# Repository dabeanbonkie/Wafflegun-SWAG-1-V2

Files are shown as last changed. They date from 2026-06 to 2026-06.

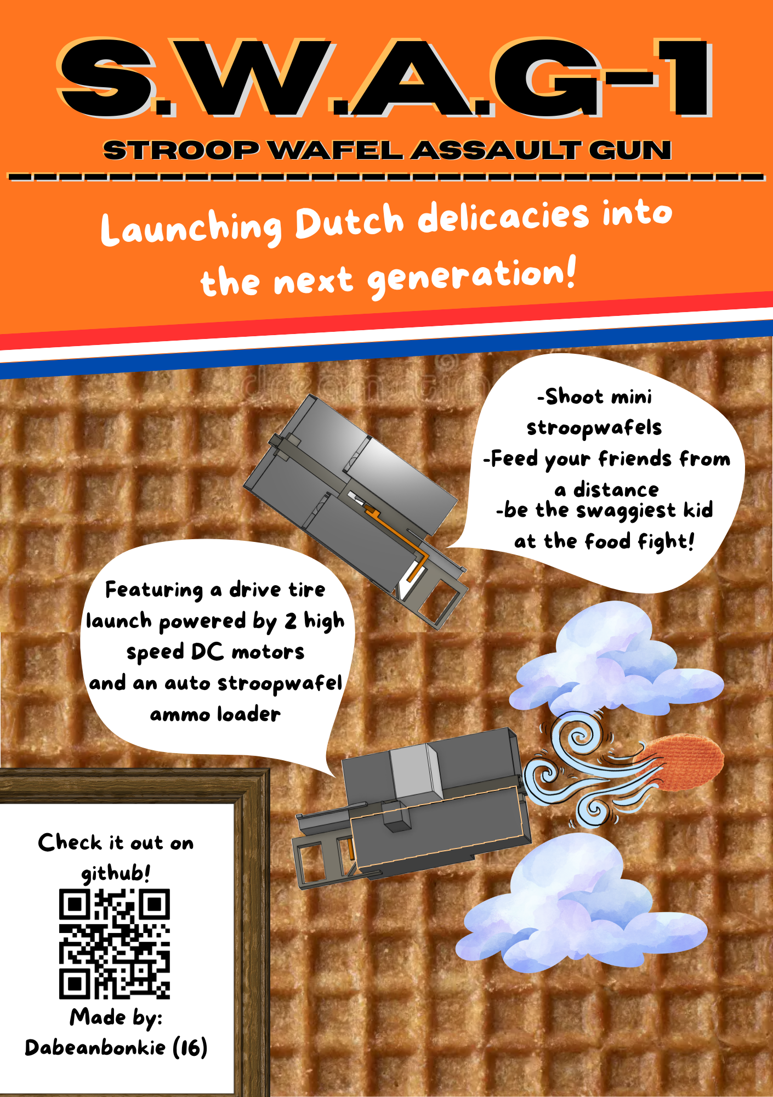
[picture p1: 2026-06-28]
S.W.A.G-1.png

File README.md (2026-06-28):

# Wafflegun-SWAG-1

S W A G-1

# Description
The S.W.A.G (Stroop-Wafel-Assault-Gun) is the latest generation of food based arms. It is a tire driven stroopwafel launcher with an auto loading system. It uses two motors for the launch and a servo for the loader and runs on a Xiao RP2040. The wafflegun can be used to hand out stroopwafels to an entire group from a distance within the span of just a couple seconds.

# Assembly
TO assemble the S.W.A.G start off by ordering the pcb from any shop you prefer, although i will explain how i ordered it using JLCPCB. Log in to JLCPCB and the hit "Order Now". From there you will be asked to add the gerber ZIP file from the repo. This will give you everything you need and the board should load on the site. Dont change anything for the rest of the order process, just hit next after you've added the gerber files zip. Following this pay for your pcb and then you're all done with the pcb until its delivered to you.

It should look like this is JLCPCB:



Note: I will be refering to the side of the pcb with the letters as the top and from there i call the other sides left, right and bottom. This is also diferent from the side of the pcb as in the working layer.

When the pcb arrives grab a BD139 NPN-transistor and place it in the holes near the left side if the pcb with the white part facing towards the inside of the pcb (pictued in example 1). Then Solder the legs of the transistor to the pcb from the bottom side while making sure no bridges are made (pictured in example 2). Then cut off the legs until the point they are soldered at (pictured in example 3)

Example 1:



Example 2:



Example 3:



Next grab all your curved pin headers, I used male dupont surved pin headers in my example because those were the ones i had, but i would recomend using female dupont curved pin headers. Both are fine so use whichever one you have but if you have to order them, order the female headers. You should have 3: 1 * 2 headers and 2: 1 * 3 headers. Put each of the pin headers in the hole that corresponds to the width (pictured in example 4). Then as with the transistor, solder each pin from the bottom side to the pcb (pictured in example 5).

Example 4:



Example 5:



Now here comes the hard part, were using a tiny 1.5K ohm SMD-0402 resistor. For the next two solders we will be using solder paste as its really the only way to get a solder this precise. I would also recomend using a magnfying glass at this point as this resistor is very small. Place two small bits of solder paste on the two pads on which we will solder the resistor (pictured in example 6). Then incredibly gently place the resistor on the two pads with the resistors black side facing up and use a heat gun to carefully melt the solder while making sure not to stay in one place too long as not to melt the pcb. The final result should look like example 7.

Example 6:



Example 7:



Lastly grab your solder paste again, and place a small glob on each of the solder pads for XIAO RP2040 (pictured in example 8). Then carefully place the XIAO RP2040 on top of the pads making sure each connection lines up with the micro-usb port facing towards the right side of the pcb (pictured in example 9). Then gently move the heatgun over the pcb to melt the solder while making sure not to melt the pcb or any other nearby components. The final result should look like example 9.

Example 8:


ELFR1021
Example 9:



You are now done with making the PCB for S.W.A.G-1

Kicad wiring schematic of the pcb:



Kicad wiring schematic of the full circuit:



To build the rest of the cuircuit start by grabbing your ELFR1021 DC high speed motors and cutting off the connector that is attached. After this crimp a dupont header on each wire of both of the motors. If you have used Female headers on the pcb, use male headers on the motors. If you have used male headers (like me) on the pcb use female headers on the motors. 

It should look like this:



After this attach red wire of both motors to the pinheaders group 5 on the pcb, and the black wires to the pinheader group 3 on the pcb.

It should look like this:



Next take your SG90 servo and attach it to pinheader group 2 on the pcb with the brown wire of the servo (GND wire) being attached to the right-sided pin on pinheader group 2. If the brown wire is on the right pin, the red and yellow wire are too.

It should look like this:



Following this i dont have a good physical example for the buttons. In the wiring diagram i show a SW-SP3T three way switch where one position is floating so no signal goes through the buttons meaning no part is turned on, and the other two positions going to either the motor or the servo so you can toggle the motor and servo separately. I do not have an SW_SP3T available due to a shipping error so the best i can do is show how to connect it. 

-First connect the right pin on pin header group 4 to the COM Pin ( also knows as the common pin and pin 3 on the wiring diagram showed earlier.). The brown wire is the wire you would connect to the common pin of the SW_SP3T.



-Then connect output 1 on the SW-SP3T to the middle pin on pinheader group 4 on the pcb and connect output 2 on the SW-SP3T to the left pin on pinheader group 4 on the pcb.

-Ouput 3 will be left floating as that will be the "off" pin so it has no output.

If you do all of this you can switch between turning on the servo, turning on the motor & having both off.

Next up take your 4*AA battery holder and if necessary crimp on female dupont headers to both wires if you have male headers on your pcb and male headers to both wires if you have female headers on your pcb.

It should look like this:


Then attach the red wire to specifically the right-sided pin on pin header ground 1 on the pcb, and the black wire to the lift sided pin  on pin header ground 1 on the pcb.

It should look like this:



With this all the wiring is done! Now on to the 3D-printed parts.

Start by printing all of the pieces in the STL files folder. The gear pieces need to be printed twice but all of the other pieces need to be printed only once.

Start by grabbing both "gear and wheel support" pieces and add 7 bearings with a 6mm inner diameter and a 13mm outer diameter to each support. Make sure to leave one hole on the far side with the extention empty as that one wont hold a gear.

It should look like this:



After that start adding your gears. Start by adding gear 1 to the first bearing from the side with the extention. Make sure to add the bearing to the flat side of the support, otherwise it will not fit.



After this add gear 2 to the bearing beside gear 1:



Then add gear 3 beside gear 2:



Then add gear 4 beside gear 3:



Then add gear 5 beside gear 4:



Then add gear A beside gear 5:



Then add gear B beside gear A:



Now repeat this exactly on the other support.

Next up, use Plastic glue to glue together barrel 1 and barrel 2. You can use glue here as these pieces never need to be seperated and are only seperate for easy of printing.

It should look roughly like this:



After this glue on the two gear and wheel support pieces making it so the side with the extention on the supports is on the wide side of the barrel with the lip. If that doesnt make sense i understand so ill show two angles of this step:





Next grab Support piece 2 with the stock attached, and slide it through the bottom square hole of the barrel. No glue required as this part might need to be seperated for maintenence. For this step i will also add 2 angles:





Then grab Support piece 1 and do the same as with support piece 2, exept this time on the top square hole and without the stock.



Following this add the PCB and Battery holder to the back of the barrel, glue is optional, you could add it if it falls off but if placed right it should fit nice and snug. For this i will again add two angles for clarity:





The next step is adding the actual electronics. First take the pcb and add it to the pcb holder (i left my battery unconnected cause its more dificult to add the pcb to the holder with the battery attached):

it should look like this:



Next add the battery on top of the pcb holder. 



After this add the motors under the extention on the gear and wheel supports, it should be a snug fit. Also remember to make sure the connector from gear 1 and the connector on the motor line up



Do the same on the other gear and wheel support.

Now add the 65mm rubber wheels to the "gear B" gears on both supports. It should be a snug fit.



Then its time to add the shells. Grab shell 1 and 2 and attach them to the barrel with them also snugly fitting around the support pieces. I will add three angles cause this can be really tricky:







Next up its time for the waffle magazine piece, i recomend laying the wafflegun on its side for this portion as the glue will dry easier without it falling if its on its side. So start off by finding the hole that the magazine attaches to and putting some plastic glue on the edges before placing on the magazine making sure that the holes are alligned on both.

This is where the hole for the magazine is:



this is how to place it:



After this its time to add the servo holder. Keep the wafflegun on its side for this part. This part has to attach right next to the the magazine. Using plastic glue, glue this part to Shell-2 as that is where the part has the largest surface area of contact.



Next up place the servo inside the servo holder, i have no physical images for this so ill try to explain how to place it. Place the servo inside the holder while making sure the wires at the back of the servo are facing the hole next to the hole for the waffle magazine.

This is the hole to put all the wires for the servo through:



Then take the wires and push them through the barrel towards the pcb, where you can connect it to the coresponding pins. The Arm of the servo should fit into the hole in the magazine itself

This is the hole the servo arm goes through:



The servo arm can then push stroopwafels into the barrel as another falls into place to replace the one thats been loaded, thus making the autoloading work.

The last piece of the puzzle is the waffle pusher, which pushes the stroopwafel to the drive tires that it gets shot from. To place it go to the side opposite of the waffle magazine  and push the long pusher piece into the hole with the tail of the piece leading to the grip and stock so you can push the waffles from where you hand is holding the S.W.A.G-1.



And now you are (finally) done with building S.W.A.G-1

# Onshape Link for the shell:

https://cad.onshape.com/documents/747ccfec51634792c2777cca/w/01fb49ed376507a91ea61a49/e/87ecc3b4d7d030e5be71dfa8

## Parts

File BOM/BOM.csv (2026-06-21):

Reference | Qty | Value | DNP | Exclude from BOM | Exclude from Board | Footprint | Datasheet
J1,J3 | 2 | Conn_01x03 |  |  |  | Connector_PinSocket_2.54mm:PinSocket_1x03_P2.54mm_Horizontal
J2,J4,J5 | 3 | Conn_01x02 |  |  |  | Connector_PinSocket_2.54mm:PinSocket_1x02_P2.54mm_Horizontal
Q1 | 1 | BD139 |  |  |  | Package_TO_SOT_THT:TO-126-3_Vertical | http://www.st.com/internet/com/TECHNICAL_RESOURCES/TECHNICAL_LITERATURE/DATASHEET/CD00001225.pdf
R1 | 1 | 1.5K |  |  |  | Resistor_SMD:R_0402_1005Metric
U1 | 1 | XIAO-RP2040-SMD |  |  |  | seeed:XIAO-RP2040-SMD

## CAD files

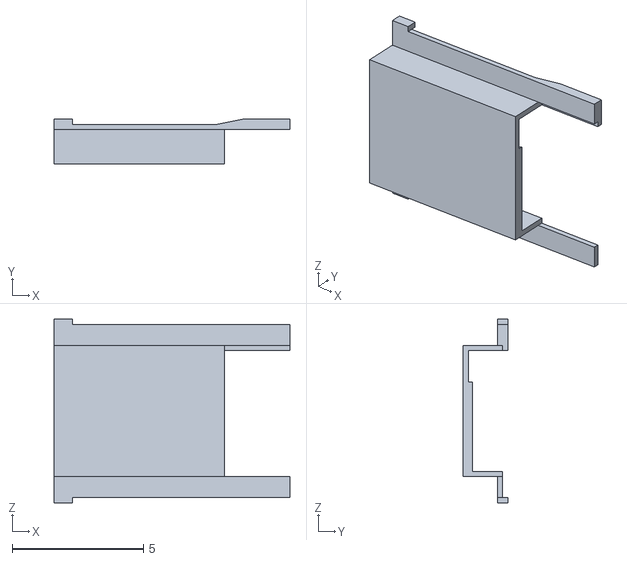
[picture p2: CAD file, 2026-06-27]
STL files Wafflegun/S.W.A.G-1 Wafflegun - PCB & Battery holder.stl
9.00 x 1.70 x 7.00

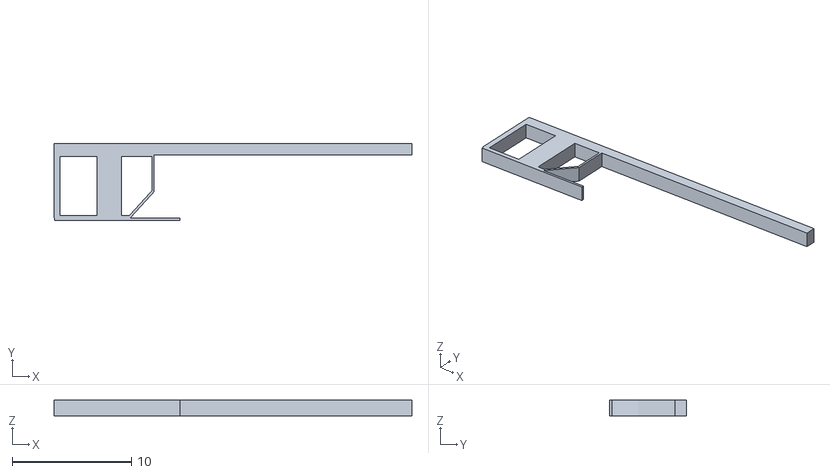
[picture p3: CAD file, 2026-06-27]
STL files Wafflegun/S.W.A.G-1 Wafflegun - Support Piece 2 + Stock.stl
30.0 x 6.42 x 1.30

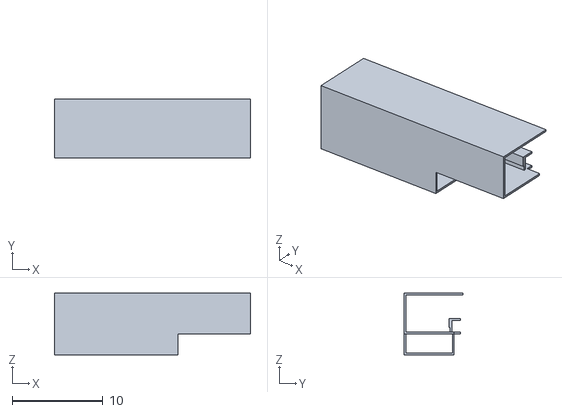
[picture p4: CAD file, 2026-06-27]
STL files Wafflegun/S.W.A.G-1 Wafflegun - Shell 2.stl
21.6 x 6.45 x 6.80

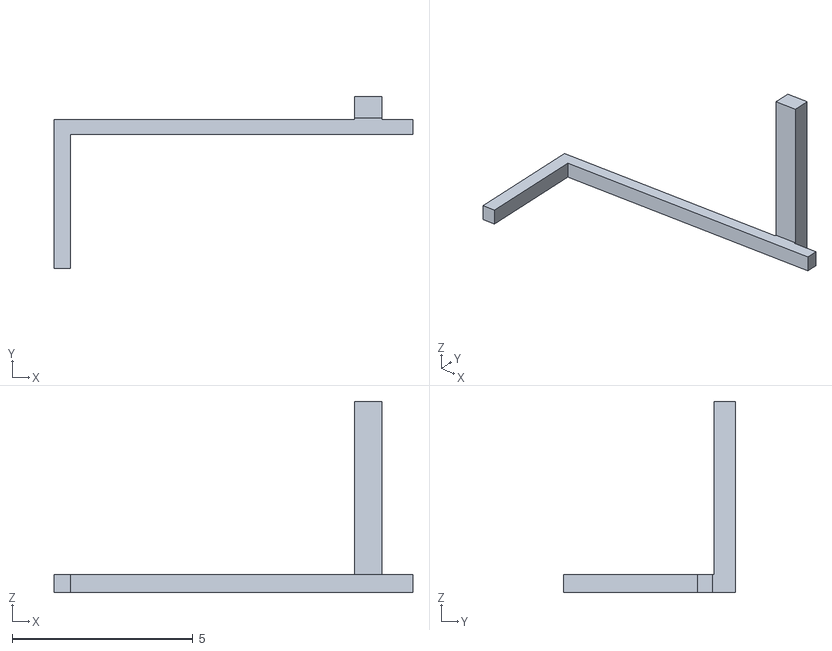
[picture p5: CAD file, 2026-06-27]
STL files Wafflegun/S.W.A.G-1 Wafflegun - Waffle pusher.stl
9.94 x 4.77 x 5.30

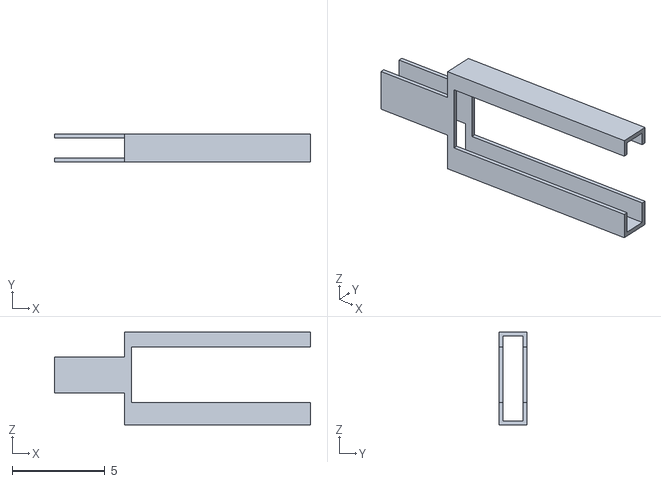
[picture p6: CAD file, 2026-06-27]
STL files Wafflegun/S.W.A.G-1 Wafflegun - Barrel 2.stl
13.8 x 1.50 x 5.00

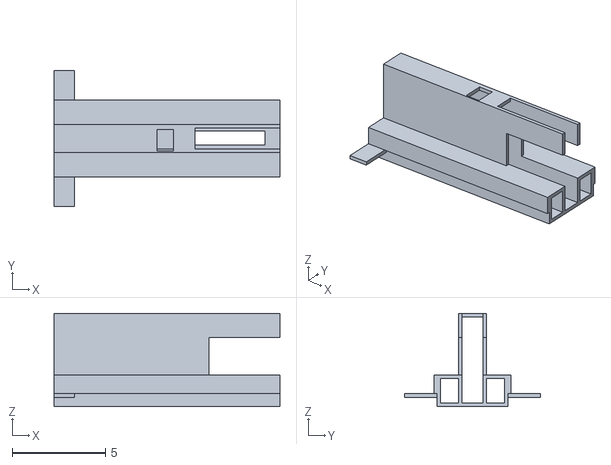
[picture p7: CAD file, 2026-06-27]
STL files Wafflegun/S.W.A.G-1 Wafflegun - Barrel 1.stl
12.1 x 7.30 x 5.00

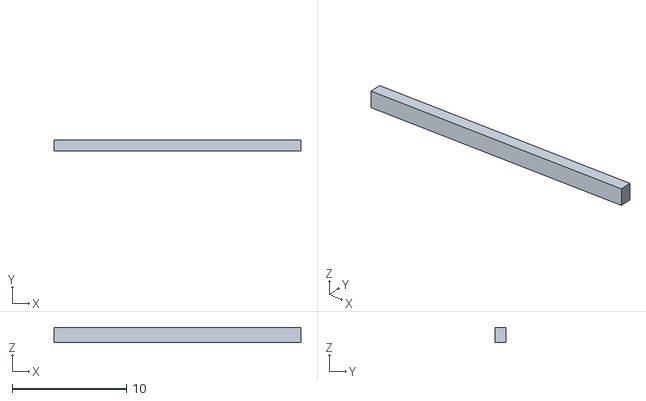
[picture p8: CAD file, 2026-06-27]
STL files Wafflegun/S.W.A.G-1 Wafflegun - Support piece 1.stl
21.6 x 0.952 x 1.30

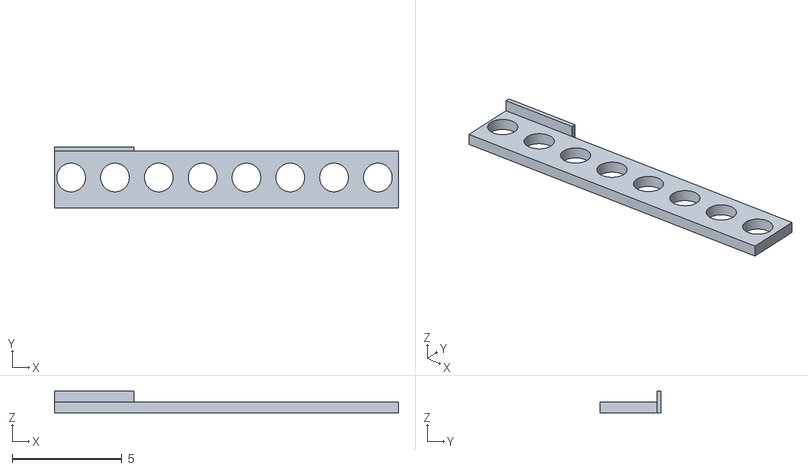
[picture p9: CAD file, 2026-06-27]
STL files Wafflegun/S.W.A.G-1 Wafflegun - Gear and Wheel Support 1.stl
15.7 x 2.80 x 1.00

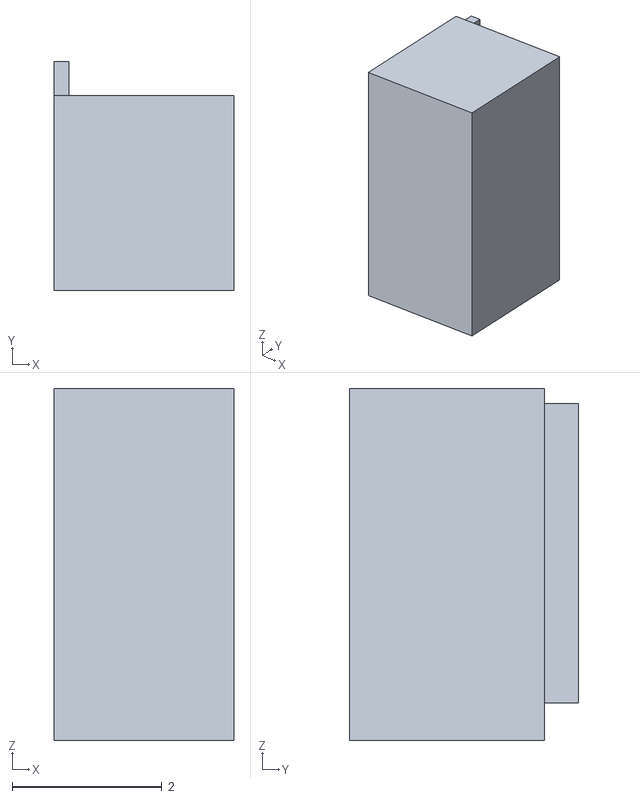
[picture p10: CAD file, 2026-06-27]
STL files Wafflegun/S.W.A.G-1 Wafflegun - Servo Holder.stl
2.40 x 3.05 x 4.70

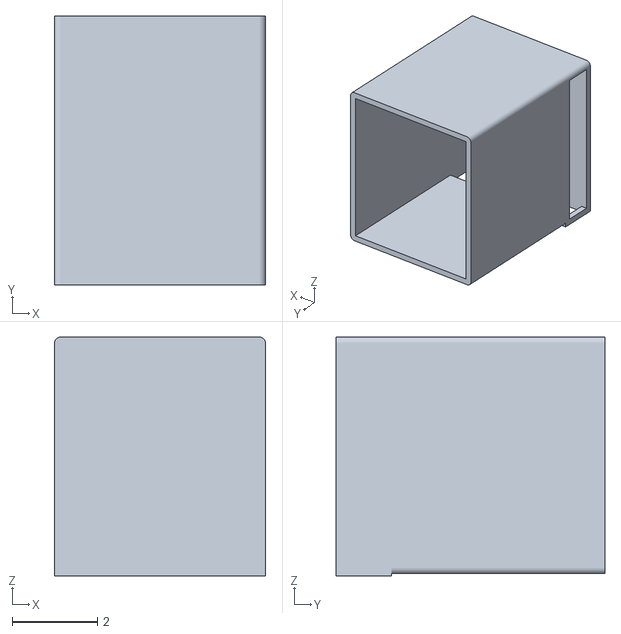
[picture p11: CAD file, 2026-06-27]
STL files Wafflegun/S.W.A.G-1 Wafflegun - Waffle Magazine.stl
4.95 x 6.30 x 5.60

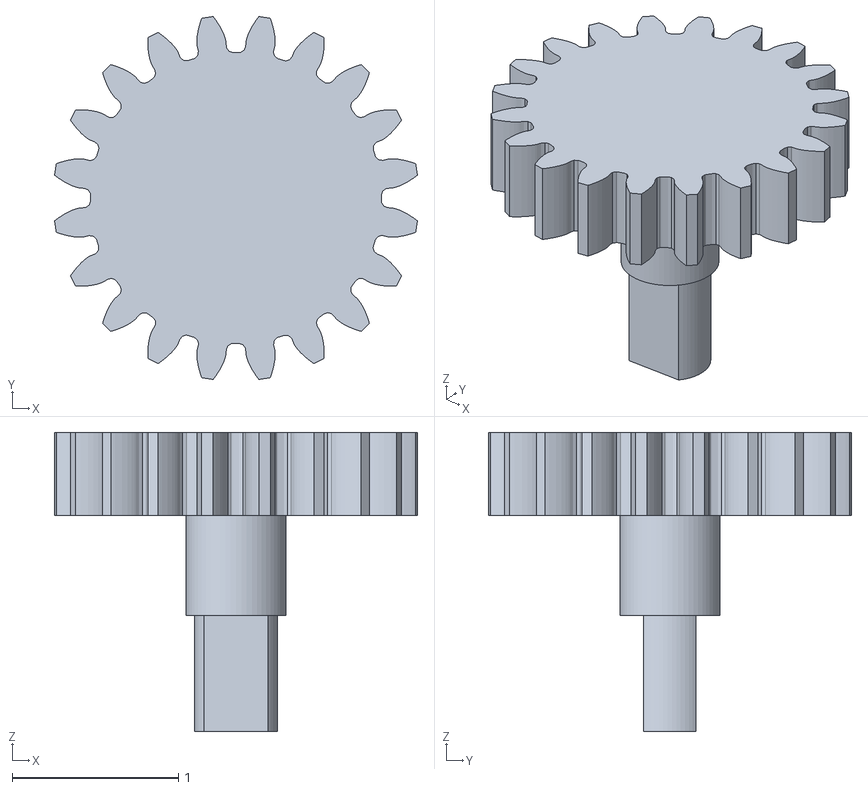
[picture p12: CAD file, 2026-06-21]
STL files Wafflegun/gear B WAFFLEGUN.stl
2.18 x 2.18 x 1.80

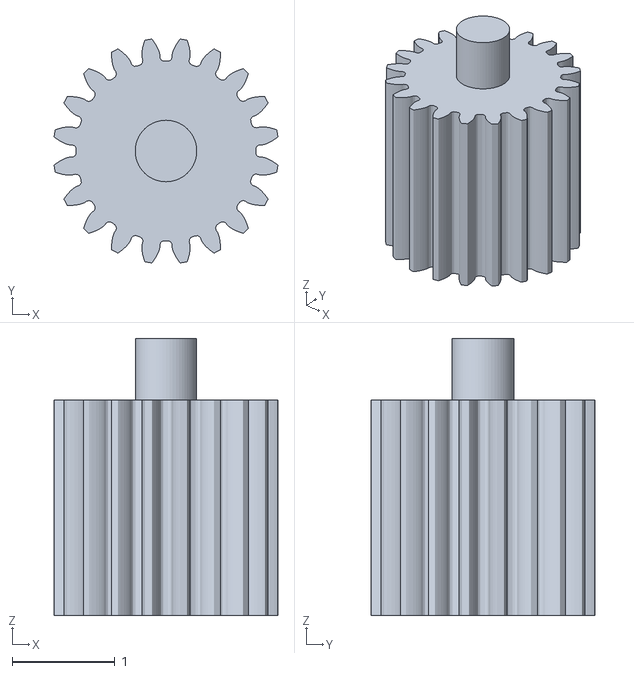
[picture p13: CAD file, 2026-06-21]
STL files Wafflegun/gear 5 WAFFLEGUN.stl
2.18 x 2.18 x 2.70

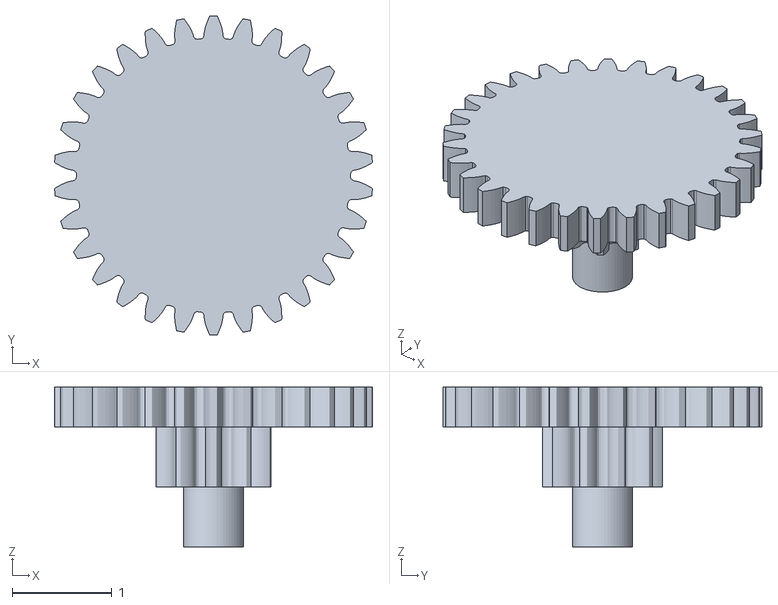
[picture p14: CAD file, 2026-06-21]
STL files Wafflegun/gear 2 WAFFLEGUN.stl
3.19 x 3.20 x 1.60

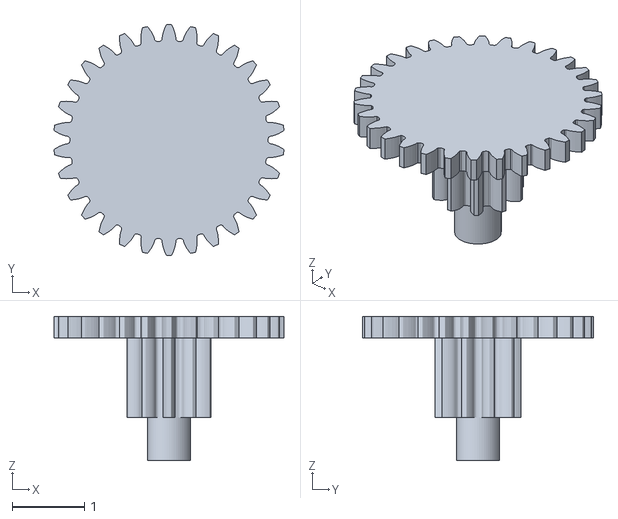
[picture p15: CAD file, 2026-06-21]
STL files Wafflegun/gear 3 WAFFLEGUN.stl
3.19 x 3.20 x 2.00

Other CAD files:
STL files Wafflegun/S.W.A.G-1 Wafflegun - Gear and Wheel Support 2.stl
STL files Wafflegun/S.W.A.G-1 Wafflegun - Shell 1.stl
STL files Wafflegun/gear A WAFFLEGUN.stl
STL files Wafflegun/gear 4 WAFFLEGUN.stl
STL files Wafflegun/gear 1 WAFFLEGUN.stl

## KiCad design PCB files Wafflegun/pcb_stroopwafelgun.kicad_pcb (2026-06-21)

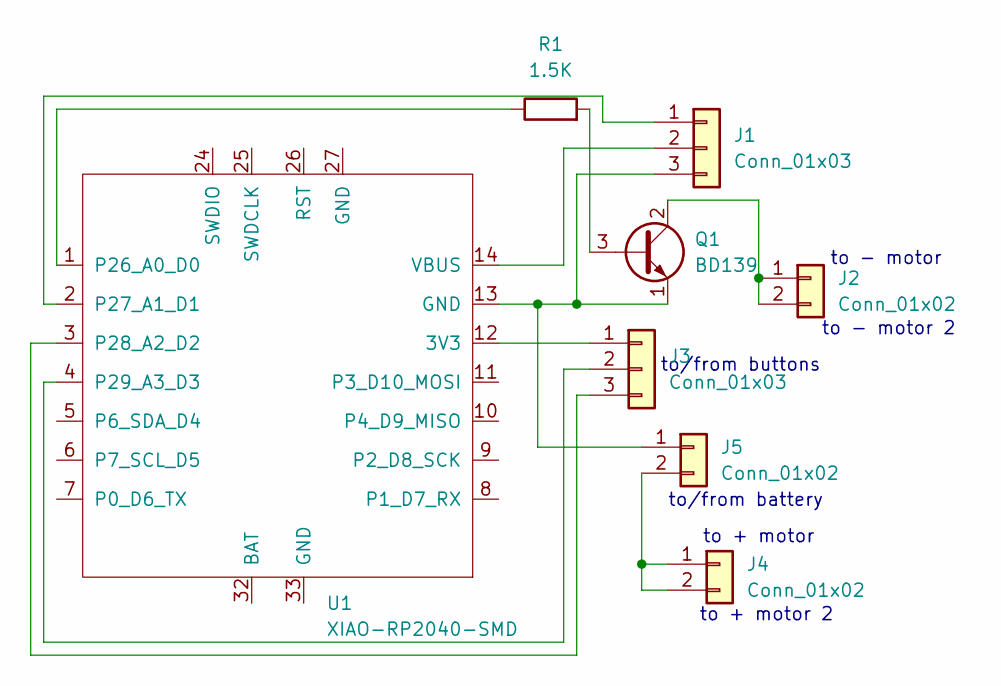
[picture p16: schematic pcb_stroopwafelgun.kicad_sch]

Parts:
J1, J3: Conn_01x03; PinSocket_1x03_P2.54mm_Horizontal
J2, J4, J5: Conn_01x02; PinSocket_1x02_P2.54mm_Horizontal
Q1: BD139; TO-126-3_Vertical
R1: 1.5K; R_0402_1005Metric
U1: XIAO-RP2040-SMD

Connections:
unnamed: J1.1, U1.2 (P27_A1_D1)
unnamed: J1.2, U1.14 (VBUS)
unnamed: J1.3, J5.1, Q1.1 (E), U1.13 (GND)
unnamed: J2.1, J2.2, Q1.2 (C)
unnamed: J3.1, U1.12 (3V3)
unnamed: J3.2, U1.4 (P29_A3_D3)
unnamed: J3.3, U1.3 (P28_A2_D2)
unnamed: J4.1, J4.2, J5.2
unnamed: Q1.3 (B), R1.2
unnamed: R1.1, U1.1 (P26_A0_D0)

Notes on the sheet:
to - motor
to + motor 2
to/from battery
to/from buttons
to - motor 2
to + motor

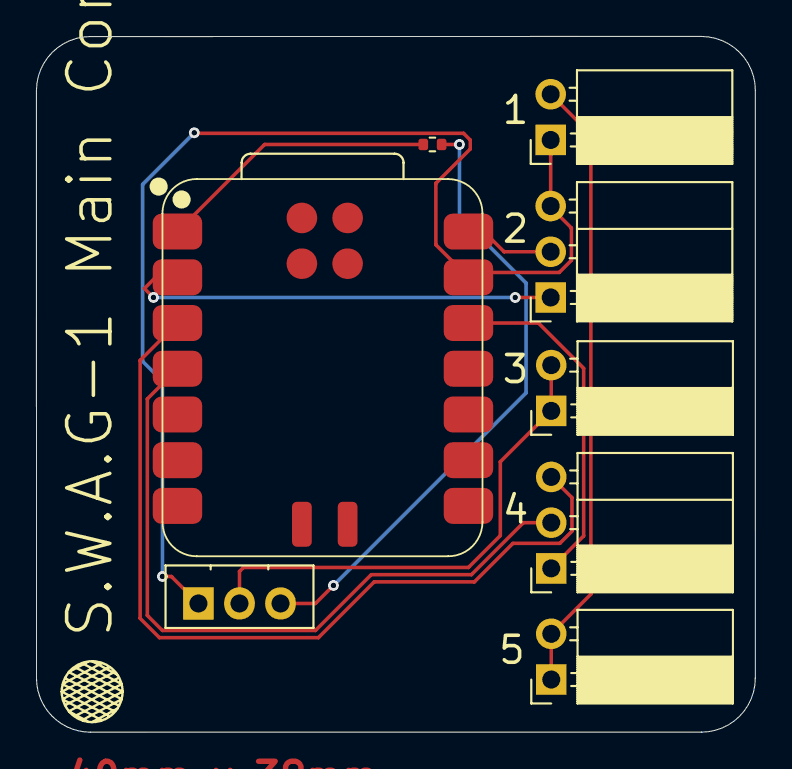
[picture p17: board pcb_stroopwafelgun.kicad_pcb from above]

Board: 2 copper layers, 39.9 x 38.7 mm, 8 parts (0 on the bottom side), 10 nets.

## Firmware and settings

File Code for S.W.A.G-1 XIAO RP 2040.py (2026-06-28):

from machine import Pin, PWM
from time import sleep
#Do I need to change the pins to fit the new board?
servo_pin = machine.Pin(27) #Xiao RP2040 Pin, Pico pin = 2
servo = PWM(servo_pin)
#button for servo
button = Pin(28, Pin.IN, Pin.PULL_DOWN) #Xiao RP2040 Pin, Pico pin = 3
motor_pin = Pin(26, Pin.OUT, value=0) #Xiao RP2040 Pin, Pico pin = 1
motor_button = Pin(29, Pin.IN, Pin.PULL_DOWN)  #Xiao RP2040 Pin, Pico pin = 5
max_duty = 8192
min_duty = 1638
frequency = 50
servo.freq(frequency)

print("before loop/hello world")

try:
    while True:
        if motor_button.value() == 1:
            print("button pressed motor")
            motor_pin.on()
            sleep(1)
            motor_pin.off()
        if button.value() == 1:
            print("button pressed servo")
            servo.duty_u16(min_duty)
            sleep(2)
            servo.duty_u16(max_duty)
            sleep(2)
        sleep(0.01)
        
       
        
except KeyboardInterrupt:
    print("Keyboard interrupt")
    servo.deinit()
   

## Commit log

2026-06-27 Rename gear 2 WAFFLEGUN (1).stl to gear 3 WAFFLEGUN.stl
    [gear 3 WAFFLEGUN.stl]
2026-06-27 Add files via upload
    COMMIT
    [S.W.A.G-1 Wafflegun - Barrel 1.stl, S.W.A.G-1 Wafflegun - Barrel 2.stl, S.W.A.G-1 Wafflegun - Gear and Wheel Support 1.stl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]
2026-06-27 Rename Gear 1 WAFFLEGUN.stl to gear 1 WAFFLEGUN.stl
    [gear 1 WAFFLEGUN.stl]
2026-06-27 Rename S.W.A.G-1 Wafflegun - PCB & Battery holder (1).stl to S.W.A.G-1 Wafflegun - PCB & Battery holder.stl
    [S.W.A.G-1 Wafflegun - PCB & Battery holder.stl]
